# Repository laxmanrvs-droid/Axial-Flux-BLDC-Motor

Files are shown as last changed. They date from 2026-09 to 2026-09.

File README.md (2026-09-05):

# Design and Fabrication of Axial Flux BLDC Motor

An engineering project covering the complete electromagnetic design, CAD modeling, hardware fabrication, and experimental validation of a 6-slot, 8-pole Axial Flux Brushless DC (BLDC) Motor.

---

## 3D Interactive CAD Model
* **[View Interactive CAD Model on Onshape](https://cad.onshape.com/documents/a40cc31149d1d09e504c31ce/w/99b5a3a0bd8f971fb47aac6b/e/8211c1ee55ab4f770ae8887e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)**

---

## Technical & Electromagnetic Specifications

| Parameter | Specification / Dimension |
| :--- | :--- |
| **Topology** | 6-Slot, 8-Pole Axial Flux Permanent Magnet BLDC |
| **Winding Configuration** | Star (Y) Connected, Single Layer |
| **Turns per Slot** | 38 Turns |
| **Wire Gauge** | 20 AWG Enamel Coated Copper Wire |
| **Winding Factor** | 0.866 |
| **Phase Resistance** | 1 Ohm |
| **Stator Outer Diameter** | 75 mm |
| **Rotor Outer Diameter** | 75 mm |
| **Slot Diameter** | 12 mm |
| **Shaft Diameter** | 6.9 mm |
| **Spool Dimensions** | Outer Diameter: 8 mm \| Inner Diameter: 6 mm |
| **Bearing Diameter** | 17 mm |
| **Structural Material** | 3D Printed PLA (Stator, Spools, Shaft, Rotor) |

---

## Working Principle & Control Pipeline

1. **Power Delivery:** An 11.1V LiPo RC battery supplies DC power to the Electronic Speed Controller (ESC).
2. **PWM Signal Generation:** An Arduino UNO generates Pulse Width Modulation (PWM) signals to command speed and direction to the ESC.
3. **Phase Conversion:** The SimonK 30A ESC converts DC power into 3-phase AC current delivered to the stator coils.
4. **Electromagnetic Interaction:** The stator produces a rotating magnetic field in the axial direction, driving the 8-pole permanent magnet rotor.
5. **Electronic Commutation:** Dynamic PWM regulation maintains continuous electronic commutation and variable speed control.

---

## Bill of Materials (BOM)

| Component | Specification |
| :--- | :--- |
| **Permanent Magnets** | Neodymium 15 x 2 mm Circular Magnets |
| **Winding Wire** | 20 AWG Enamel Coated Copper Wire |
| **3D Printed Structure** | PLA Stator Body, Spools, Shaft, Rotor |
| **Speed Controller** | SimonK 30A Electronic Speed Controller (ESC) |
| **Microcontroller** | Arduino UNO |
| **Power Source** | 11.1V LiPo RC Battery |

---

## Testing & Oscilloscope Results

* **Equipment Used:** Rigol DS1054Z Digital Oscilloscope.
* **Waveform Validation:** Confirmed a clean 3-phase sinusoidal back-EMF profile.
* **Phase Alignment:** Verified the expected 120-degree phase shift across all three phases during rotation.

---

## Engineering Challenges & Solutions

* **ESC Overheating:** Solved by transitioning from constant signal drive algorithms to smooth, incremental PWM speed regulation via Arduino.
* **Rotor Jerks & Synchronization:** Iteratively tested multiple pole arrangements (8 mm magnets at 10-pole, 4-pole, and 8-pole) before optimizing to **15 mm magnets in an 8-pole configuration**, significantly enhancing magnetic flux distribution and operational stability.

---

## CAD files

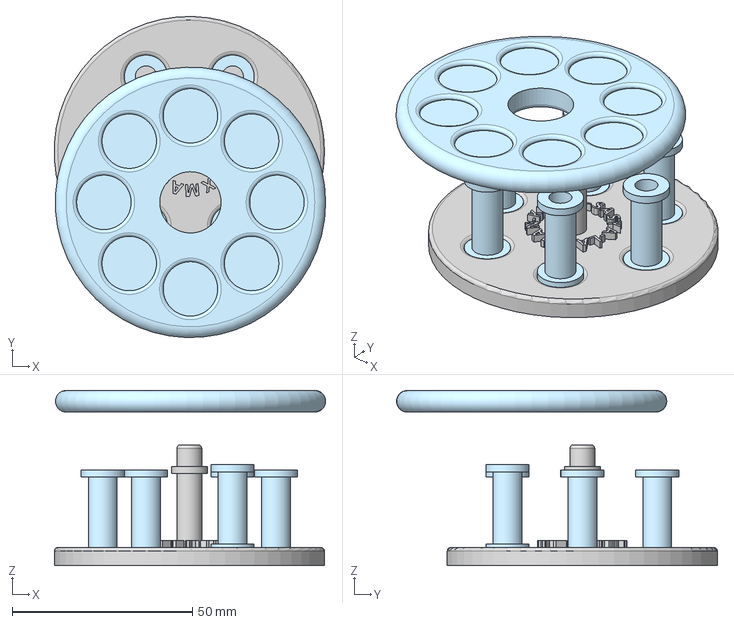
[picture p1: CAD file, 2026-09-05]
Motor_Assembly_Final.step
75.2 x 89.0 x 48.6 mm

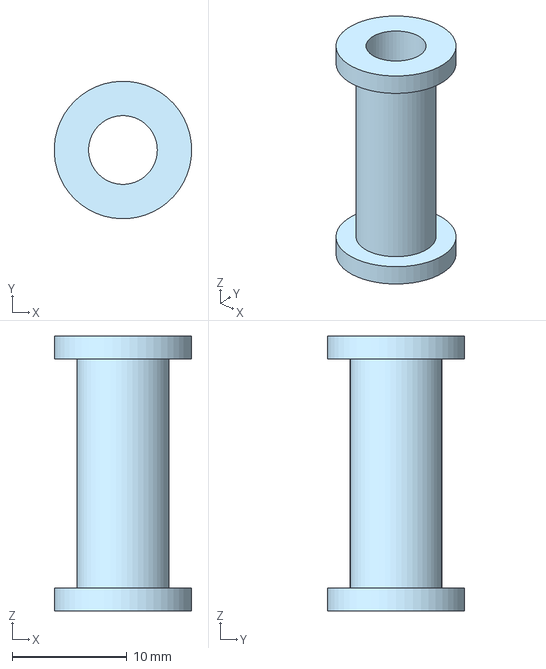
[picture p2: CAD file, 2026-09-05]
Spool_Final.step
12.0 x 12.0 x 24.0 mm

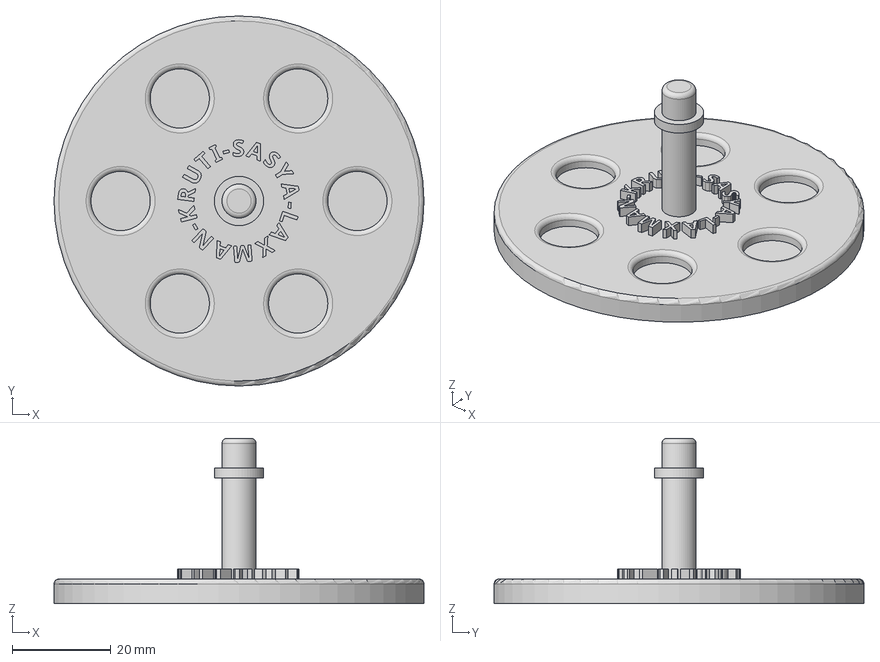
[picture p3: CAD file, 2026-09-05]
Stator_Final.step
75.0 x 75.0 x 33.5 mm

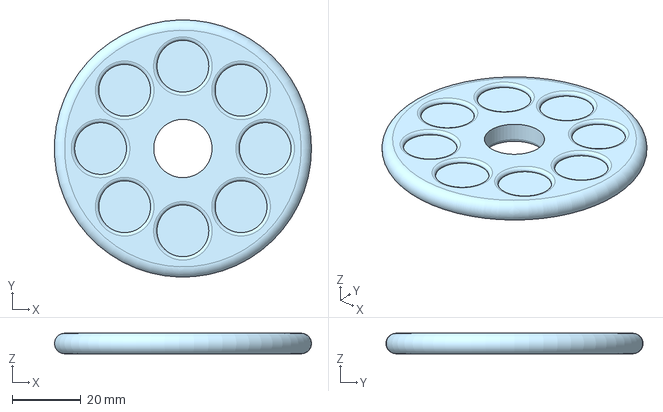
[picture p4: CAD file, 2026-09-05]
Rotor_Final.step
74.9 x 75.0 x 6.00 mm
